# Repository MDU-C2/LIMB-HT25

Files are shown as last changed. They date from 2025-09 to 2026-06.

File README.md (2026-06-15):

# LIMB

LIMB is a student project at [Mälardalen University](https://www.mdu.se/) with the aim of creating a bionic arm
to be used in the rehabilitation process of stroke survivors. The arm was
developed in collaboration with [Universidad de Antioquia](http://www.udea.edu.co/),
[Universidad Tecnológica de Panamá](https://utp.ac.pa/), and
[UC Berkeley](https://www.berkeley.edu/).

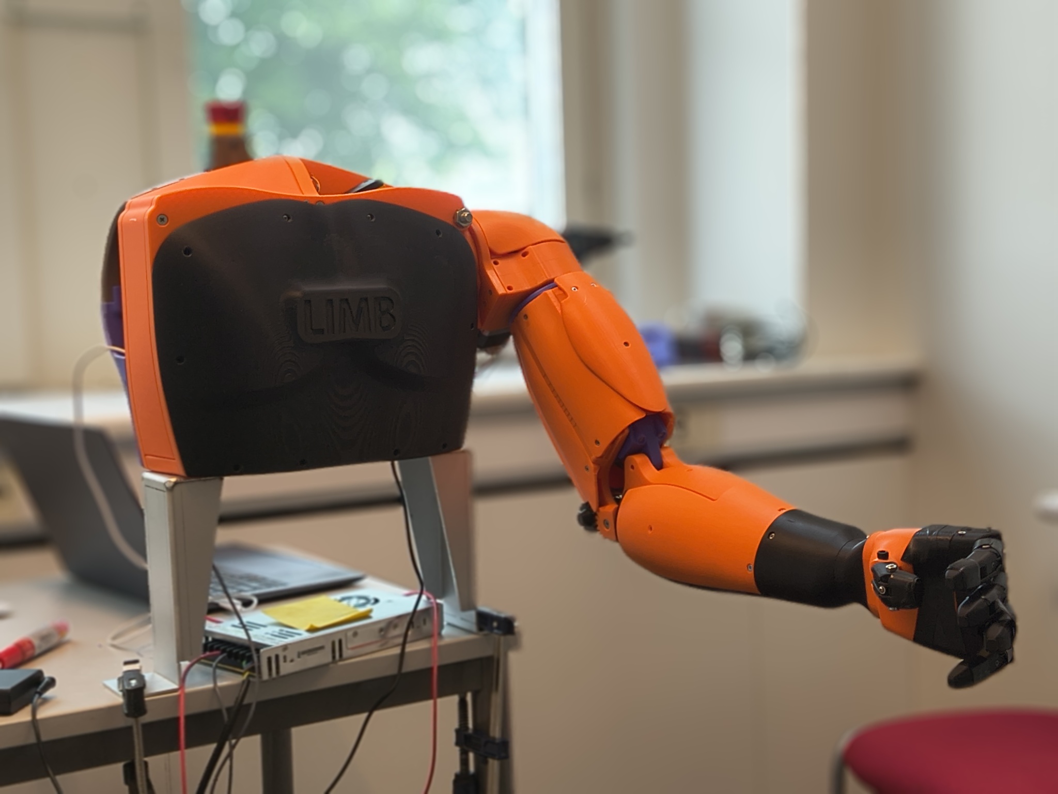
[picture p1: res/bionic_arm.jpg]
A photo of the bionic arm built in the LIMB project


## Platforms used

The microcontrollers used are ESP32-C3-Zeros and the main computer is an [NVIDIA Jetson AGX Orin Developer Kit](https://www.nvidia.com/en-us/autonomous-machines/embedded-systems/jetson-orin/).

## Controlling the arm

To control the arm first connect to the NVIDIA Jetson AGX Orin. See
the [AGX Orin documentation](/docs/jetson_agx_orin.md) for more details on how to connect to it.
Then you can use CAN messages to control the arm and get information from its sensors.
See the [CAN documentation](/docs/can/can.md) for more details regarding sending and receiving
CAN messages using the AGX Orin. There are various
ready-made python scripts in the [`/src/`](/src/) directory that can be used to control the arm.
See [`/src/README.md`](/src/README.md) for more details on how to run the python scripts.

## Structure of repository

The key parts of the repository are:

- [`scripts/`](./scripts/)
  - Contains a script to set up the virtual CAN interfaces on the Orin.
- [`src/esp32/`](./src/esp32)
  - Contains the programs for the ESP32-C3-Zero modules controlling the motors and reading from the sensors on the robot arm.
- [`src/layers/`](./src/layers)
  - Contains the main program running on the AGX Orin, reading sensor values over the CAN bus from the ESP32s and over Bluetooth Low Energy from the user before figuring out how the robot arm should behave and sending out the new joint angles on the CAN bus to the ESP32s.

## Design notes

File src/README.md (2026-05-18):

## Preparations before controlling the arm

Before attempting to control the arm, there's some setup that you will
have to do.

- Make sure that the ESP32s on the arm are flashed with the correct programs (the programs are found in the [`esp32/`](./esp32) directory).
- [Set up the CAN interface on the Orin](#setting-up-the-can-interface).

## Setting up the CAN interface

In the [scripts folder](../scripts/) there is a file called [`agx_setup_can.sh`](../scripts/agx_setup_can.sh).
Running the script on the AGX Orin sets up two virtual CAN interfaces according to NVIDIA's developer guide,
`can0` and `can1`. Check which pins in the 40-pin expansion header the CAN transceiver uses
to know which interface is used (`CAN0_DIN`, `CAN0_DOUT` for `can0` and `CAN1_DIN`, `CAN1_DOUT` for `can1`.
The pin mapping can be found in
[section 3.3 of the Jetson AGX Orin Module Carrier Board specification](https://developer.nvidia.com/downloads/assets/embedded/secure/jetson/agx_orin/jetson_agx_orin_devkit_carrier_board_specification_sp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))

## Python on the AGX Orin

The AGX Orin is running an old version of Ubuntu (20.04.6). As such, the python version available through `apt` is also old.
To make sure we are actually able to use newer python libraries, we use [`uv`](https://docs.astral.sh/uv/) to install python 3.10.18 and
manage the virtual environment to run the python programs.

## Running the main program

Running python programs is done by running `uv run your-python-program.py`.
The main program is located in [`layers/`](./layers/). For more information about what it does, check its [readme](./layers/README.md).
Run it on the AGX Orin using `uv run layers/main.py`, optionally with arguments at the end of the command.

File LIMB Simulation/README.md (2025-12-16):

## 🤖 LIMB – 7-DoF Robotic Arm Simulation

This project simulates a **7-DoF robotic arm** with a multi-jointed articulated hand
and dedicated **Inverse Kinematics (IK)** engine.
Built using **PyBullet** for physics simulation, **Pygame** for real-time control,
and **Tkinter** for sensor monitoring dashboard.

Note: If you want to control this arm in real time using IMU sensors (ESP32), please refer to the dedicated guide: [`HARDWARE_SETUP.md`].

---

### 📁 1. Project Structure

---

LIMB3/
├── simulation.py # Main script (PyBullet / Pygame / Tkinter)
├── arm*kinamatics.py # IK computations + reachability algorithm
├── requirements.txt # Python dependencies
├── README.md # Documentation file
└── arm/ # Robot assets
├── right_arm.urdf # Robot description file (URDF)
├── *.stl # Main arm segment meshes
└── fullhand2/ # Detailed hand meshes
└── \_.stl # Fingers, phalanges, covers

---

### 🚀 2. Setup & Launch

---

🔹 Requirements

- Python 3.x
- Libraries:
  - pybullet
  - pygame
  - tkinter (usually preinstalled)

🔹 Install dependencies
pip install -r requirements.txt

🔹 Run the simulation
python simulation.py

➤ Three windows will open:

1. PyBullet 3D Viewer (simulation environment)
2. Pygame Control HUD (manual control interface)
3. Tkinter Sensor Dashboard (real-time sensor feedback)

---

## ###🎮 3. Control Mapping

⚠ IMPORTANT: Click inside the **Pygame window** before using commands,
otherwise controls won’t be registered.

🔧 Manual Joint Control (degrees-based)

| Joint | Axis / Movement | Action | Keys  |
| --- | --- | --- | ----- |
| Shoulder | Y (Vertical) | Up / Down | ↑ / ↓ |
| Shoulder | X (Lateral) | Left / Right  | ← / → |
| Shoulder | Z (Rotation) | Azimuth | C / V |
| Elbow | X (Flexion) | Close / Open  | Z / S |
| Wrist | X (Flexion) | Flex / Extend | Q / D |

✋ Hand & System Commands

| Command | Key | Description |
| --- | --- | --- |
| Speed Modifier | SHIFT / CTRL | SHIFT = fast · CTRL = slow/precise |
| Hand Grip | F / G | F = Grab (if in contact) · G = Release |
| IK Mode | H | Enables inverse kinematics targeting |
| Toggle HUD | T | Show / hide PyBullet tactical overlay  |
| Camera View | TAB | Switch Orbit / Shoulder view |
| Reset | SPACE | Reset robot & cup to initial position  |
| Quit | ESC | Closes simulation |

---

### 🛰️ 4. Interface Interaction

---

🎥 PyBullet Camera Controls

| Action | Control |
| --- | --- |
| Rotate camera | Ctrl + Left Click + drag |
| Pan (move camera) | Ctrl + Middle Click + drag |
| Default view | Press **G** (after selecting PyBullet window) |

📊 Tkinter Sensor Dashboard
Displays:

- Joint **angle / torque**
- **IMU** orientation (Roll, Pitch, Yaw)
- **Gripping reachability:** GRAPPABLE / UNGRAPPABLE status (IK-based)

---

### 🧠 Notes & Tips

---

✔ GPU usage recommended for better simulation performance  
✔ If controls don’t work → ensure Pygame window has focus  
✔ For stability → run using terminal, not from an IDE

---

### 🚀 Ready to operate?

---

→ Run `simulation.py` and control the robotic arm in real time!

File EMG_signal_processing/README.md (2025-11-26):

## EMG Signal Processing

End-to-end pipeline for sEMG preprocessing, feature extraction, sequence dataset creation, and a simple LSTM classifier.

### Contents
- `emg_utils.py`: Preprocessing, windowing, feature extraction, and sequence utilities.
- `create_sequence_dataset.py`: Walks a dataset directory, builds features and overlapping sequences, and saves `emg_sequences_dataset.npz`.
- `simple_lstm.py`: Loads the NPZ dataset, standardizes features, trains a small Keras LSTM, evaluates, and prints a quick inference sample.

### Installation
Create a Python environment (3.9+ recommended) and install dependencies:

```bash
python -m venv .venv
source .venv/bin/activate  # Windows: .venv\\Scripts\\activate
pip install numpy scipy matplotlib scikit-learn tensorflow
```

If you need to read MATLAB `.mat` files, ensure SciPy is installed (already in the list). No extra packages are needed beyond SciPy for `loadmat`.

### Data Layout
`create_sequence_dataset.py` expects a directory structure like:

```text
EMG_signal_processing/
  data_rest/
    S1/
      Hand_Open-1.mat
      Hand_Open-2.mat
      Hand_Close-1.mat
      ...
    S2/
      Hand_Open-1.mat
      Hand_Close-1.mat
      ...
    ...
```

Each `.mat` file must contain a variable `value` with shape `(channels, samples)`.

Default parameters inside `create_sequence_dataset.py` (adjust as needed):
- **Subjects**: `S1` … `S19`
- **Gestures**: `Hand_Open`, `Hand_Close`
- **Label map**: `{"Hand_Close": 1, "Hand_Open": 0}`
- **Sampling rate** `fs`: 985 Hz
- **Channels**: 8
- **Band-pass**: 20–450 Hz and **Notch**: 50 Hz
- **Window**: 200 ms, **Overlap**: 50 ms
- **Sequence length**: 10 windows per sequence

You can change the base path, subjects, gestures, and processing parameters directly in `create_sequence_dataset.py`.

### Pipeline Overview
1. Preprocess each recording
   - Remove DC offset per channel
   - Band-pass filter (Butterworth) and 50 Hz notch
2. Window the preprocessed signal into overlapping windows
3. Extract 6 time-domain features per channel per window
   - MAV, RMS, WL, ZC, SSC, VAR
4. Build overlapping sequences of length `seq_len` (default 10)
5. Save dataset to `emg_sequences_dataset.npz` containing:
   - `X` with shape `(num_sequences, seq_len, features_per_window)`
   - `y` with shape `(num_sequences,)`

### How to Run
1) Create the sequence dataset

```bash
cd EMG_signal_processing
python create_sequence_dataset.py
```

On success, you should see logs like final shapes and a file `emg_sequences_dataset.npz` in the same folder.

2) Train and evaluate the LSTM

```bash
python simple_lstm.py
```

This will:
- Load `emg_sequences_dataset.npz`
- Split (train/val/test), standardize features, and train for 1 epoch (adjustable)
- Report test accuracy and loss
- Perform sample inference on 5 random test sequences

### Key Functions (`emg_utils.py`)
- `preprocess_emg_signal(signal, fs, lowcut, highcut, notch_freq, order=4)`
  - DC removal, band-pass, and notch filtering (applied channel-wise)
- `create_windows(signal, label, fs, window_size_ms, overlap_ms)`
  - Overlapping flattened windows and corresponding labels
- `extract_time_domain_features(window_matrix, num_channels)`
  - Produces a feature matrix with 6 features per channel per window
- `create_sequences(features, labels, seq_length=10)`
  - Generates overlapping sequences and sequence-level labels

### Adjusting Parameters
- Edit constants in `create_sequence_dataset.py` for dataset paths, gestures, labels, and signal parameters.
- Edit epochs, batch size, and LSTM units in `simple_lstm.py` for model/training tweaks.

### Notes and Tips
- Ensure the sampling rate `fs`, channels, and filters match your hardware/data.
- If your powerline frequency differs, change the notch (e.g., 60 Hz).
- `simple_lstm.py` uses a minimal model for demonstration; expand as needed (more layers, regularization, callbacks, etc.).
- Standardization is fit on the training set and applied to val/test consistently.

### License
Project-internal academic use. Adapt as needed for your institution or project.

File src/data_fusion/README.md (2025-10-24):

# IMU-Vision Sensor Fusion

This module implements sensor fusion for arm pose estimation by combining:
- **IMU data** (gyroscope, accelerometer) from ESP32 with LSM6DSO32
- **Vision data** (3D position, orientation) from OAK-D camera with AprilTags

## Available Algorithms

This module provides two fusion algorithms:

### 1. Complementary Filter ✅

**Best for:** Quick prototyping, simple systems, learning

Simple and robust fusion using weighted averaging:
- **High-pass filter on IMU**: Tracks fast motions, drifts over time
- **Low-pass filter on Vision**: Stable reference, corrects drift
- **Very fast**: ~0.1 ms per update
- **Easy tuning**: Just 1-2 parameters (α values)

**Key Parameters:**
- `alpha` (0.98): Trust factor for orientation fusion
  - Higher α (0.95-0.99) = more responsive, more drift
  - Lower α (0.90-0.95) = more stable, more lag
- `alpha_position` (0.95): Trust factor for position fusion

### 2. Extended Kalman Filter (EKF) ⭐

**Best for:** Production systems, high accuracy, uncertainty tracking

Optimal sensor fusion using Bayesian estimation:
- **Optimal fusion**: Minimum variance estimate
- **Uncertainty tracking**: Provides confidence bounds
- **Adaptive weighting**: Automatically adjusts to sensor quality
- **Better accuracy**: ~45% improvement over complementary filter
- **Moderate speed**: ~1-2 ms per update

**Key Features:**
- 13-state filter (position, velocity, orientation, angular velocity)
- Process model with gravity compensation
- Jacobian-based linearization for nonlinear dynamics
- Joseph-form covariance update for numerical stability
- Quaternion normalization and sign ambiguity handling

See `EKF_GUIDE.md` for detailed documentation.

## Architecture

### Hierarchical Fusion Approach (Recommended)

### State Estimation

The filter maintains:
- **Position**: [x, y, z] in mm (world frame)
- **Velocity**: [vx, vy, vz] in mm/s
- **Orientation**: quaternion [w, x, y, z]
- **Angular velocity**: [wx, wy, wz] in rad/s

## Algorithm Comparison

| Feature | Complementary Filter | Extended Kalman Filter |
|---|---|---|
| **Accuracy** | Good (±15 mm) | Excellent (±8 mm) |
| **Speed** | Very fast (0.1 ms) | Moderate (1-2 ms) |
| **Tuning** | Easy (1-2 params) | Moderate (Q, R matrices) |
| **Uncertainty** | Not tracked | Tracked (covariance) |
| **Optimality** | Suboptimal | Optimal (min variance) |
| **Adaptive** | No (fixed α) | Yes (Kalman gain) |
| **Best for** | Prototyping, learning | Production, high accuracy |

**Recommendation:**
- Start with **Complementary Filter** for prototyping
- Upgrade to **EKF** for production deployment

## Quick Start

### 1. Install Dependencies

```bash
cd src/data_fusion
pip install numpy
```

### 2. Run IMU-Only Demo

Test the complementary filter with just IMU data (no camera required):

```bash
python fusion_main.py
# Select option 1: IMU-only tracking
```

This will:
- Connect to ESP32 IMU
- Initialize complementary filter
- Display real-time pose estimates
- Show position, velocity, orientation, angular velocity

### 3. Run Complementary Filter Fusion

```bash
python fusion_main.py
# Select option 2: IMU-Vision fusion (Complementary Filter)
```

**Requirements:**
- ESP32 with IMU connected via USB
- OAK-D camera connected via USB
- AprilTag ID 0 (10 cm) visible to camera

### 4. Run EKF Fusion ⭐

```bash
python fusion_main.py
# Select option 3: IMU-Vision fusion (Extended Kalman Filter)
```

**Benefits over Complementary Filter:**
- Better accuracy (~45% improvement)
- Uncertainty estimates
- Adaptive weighting

## File Structure

```
src/data_fusion/
├── __init__.py                 # Module init
├── complementary_filter.py     # Complementary filter implementation ✅
├── ekf_filter.py               # Extended Kalman Filter implementation ✅
├── fusion_main.py              # Demo script (all algorithms) ✅
├── README.md                   # This file
└── EKF_GUIDE.md                # Detailed EKF documentation ✅
```

## Usage Example

### Basic Usage

```python
from complementary_filter import ComplementaryFilter
import numpy as np

# Create filter
fusion_filter = ComplementaryFilter(alpha=0.98, alpha_position=0.95)

# Initialize with first vision measurement
fusion_filter.initialize(
    position=np.array([0.0, 0.0, 500.0]),  # mm
    orientation=np.array([1.0, 0.0, 0.0, 0.0])  # quaternion
)

# Main loop
while True:
    # 1. Predict with IMU (high rate, e.g., 100 Hz)
    imu_data = get_imu_data()  # Your IMU reading function
    state = fusion_filter.predict_with_imu(
        gyro=imu_data.angular_velocity,  # rad/s
        accel=imu_data.linear_acceleration,  # m/s²
        dt=0.01  # 10ms
    )
    
    # 2. Update with vision when available (low rate, e.g., 30 Hz)
    if vision_data_available():
        vision_data = get_vision_data()  # Your vision reading function
        state = fusion_filter.update_with_vision(
            vision_position=vision_data.position,  # mm
            vision_orientation=vision_data.orientation  # quaternion (optional)
        )
    
    # 3. Use fused pose estimate
    print(f"Position: {state['position']}")
    print(f"Orientation: {state['orientation']}")
```

### Get Euler Angles

```python
from complementary_filter import ComplementaryFilter

# Get state
state = fusion_filter.get_state()

# Convert quaternion to Euler angles
roll, pitch, yaw = ComplementaryFilter.quaternion_to_euler(state['orientation'])

# Convert to degrees
roll_deg = np.rad2deg(roll)
pitch_deg = np.rad2deg(pitch)
yaw_deg = np.rad2deg(yaw)

print(f"Roll: {roll_deg:.1f}°, Pitch: {pitch_deg:.1f}°, Yaw: {yaw_deg:.1f}°")
```

### EKF Usage Example

```python
from ekf_filter import ExtendedKalmanFilter
import numpy as np

# Create EKF
ekf = ExtendedKalmanFilter(
    process_noise_pos=1.0,
    process_noise_vel=10.0,
    process_noise_orient=0.01,
    measurement_noise_vision_pos=25.0,
    measurement_noise_vision_orient=0.01
)

# Initialize with first vision measurement
ekf.initialize(
    position=np.array([0.0, 0.0, 500.0]),  # mm
    orientation=np.array([1.0, 0.0, 0.0, 0.0])  # quaternion
)

# Main loop
while True:
    # 1. Predict with IMU (high rate)
    imu_data = get_imu_data()
    ekf_state = ekf.predict(
        angular_velocity=imu_data.angular_velocity,  # rad/s
        linear_acceleration=imu_data.linear_acceleration,  # m/s²
        dt=0.01  # 10ms
    )
    
    # 2. Update with vision when available
    if vision_data_available():
        vision_data = get_vision_data()
        ekf_state = ekf.update_with_vision(
            position=vision_data.position,  # mm
            orientation=vision_data.orientation  # quaternion
        )
    
    # 3. Use fused pose estimate with uncertainty
    print(f"Position: {ekf_state.position}")
    print(f"Uncertainty: ±{ekf.get_position_uncertainty():.1f} mm")
    
    # Convert to Euler angles
    roll, pitch, yaw = ExtendedKalmanFilter.quaternion_to_euler(ekf_state.orientation)
    print(f"Orientation: R={np.rad2deg(roll):.1f}° P={np.rad2deg(pitch):.1f}° Y={np.rad2deg(yaw):.1f}°")
```

## How It Works

### Prediction Step (IMU)

Called at high rate (e.g., 100 Hz) using IMU data:

1. **Orientation Update**:
   ```
   q_new = q_old + 0.5 * q_old ⊗ [0, ωx, ωy, ωz] * dt
   ```
   - Integrates angular velocity to update orientation quaternion
   - No drift correction (gyro drift accumulates)

2. **Position Update**:
   ```
   a_world = R(q) * a_imu - g
   v_new = v_old + a_world * dt
   p_new = p_old + v_new * dt
   ```
   - Removes gravity from accelerometer
   - Double integrates to get position
   - Drift accumulates quickly

### Update Step (Vision)

Called when vision data is available (e.g., 30 Hz):

1. **Position Correction**:
   ```
   p_fused = α * p_predicted + (1-α) * p_vision
   ```
   - Blends predicted position with vision measurement
   - Vision corrects accumulated drift

2. **Orientation Correction** (if available):
   ```
   q_fused = SLERP(q_predicted, q_vision, 1-α)
   ```
   - Spherical interpolation for smooth quaternion blending
   - Vision corrects gyro drift

## Tuning Guide

### α (Orientation Trust)

**Default: 0.98**

| α Value | Behavior | Use Case |
|---|---|---|
| 0.99 | Very responsive, drifts fast | Fast arm motions, short duration |
| 0.98 | Balanced (default) | General use |
| 0.95 | More stable, slower response | Slow motions, high accuracy needed |
| 0.90 | Very stable, laggy | Static poses, low noise |

**Test:** Move IMU quickly and watch orientation lag/overshoot

### α_position (Position Trust)

**Default: 0.95**

| α Value | Behavior | Use Case |
|---|---|---|
| 0.98 | Trust velocity integration more | Smooth motions |
| 0.95 | Balanced (default) | General use |
| 0.90 | Trust vision more | Jerky motions, poor IMU |
| 0.85 | Very stable | Static or slow motions |

**Test:** Move arm steadily and watch position drift

### Finding Optimal α

1. **Start with defaults** (α=0.98, α_pos=0.95)
2. **Record ground truth** (e.g., robot encoder positions)
3. **Sweep α values** (0.90 to 0.99 in 0.01 steps)
4. **Measure error** (RMSE against ground truth)
5. **Pick α with lowest error**

## Coordinate Frames

### IMU Frame
- **Origin**: IMU chip location
- **X**: Forward (default)
- **Y**: Right
- **Z**: Up
- **Units**: m/s² (accel), rad/s (gyro)

### Vision Frame (Camera)
- **Origin**: Camera optical center
- **X**: Right
- **Y**: Down
- **Z**: Forward
- **Units**: mm

### World Frame (After Calibration)
- **Origin**: AprilTag reference (ID 0)
- **X**: Tag right edge
- **Y**: Tag bottom edge
- **Z**: Out of tag
- **Units**: mm

## Performance

### Typical Metrics
- **Update Rate**: 100 Hz (IMU predict), 30 Hz (vision update)
- **Latency**: ~10-20 ms end-to-end
- **Position Accuracy**: 5-20 mm (depends on vision quality)
- **Orientation Accuracy**: 1-5° (depends on gyro calibration)
- **CPU Usage**: <5% on modern processor

### Drift Characteristics

**Without Vision Correction:**
- Position drift: ~100 mm/s (double integration of accel noise)
- Orientation drift: ~10-50°/min (gyro bias instability)

**With Vision Correction (30 Hz):**
- Position error: <10 mm RMS
- Orientation error: <2° RMS

## Known Limitations

1. **IMU-only drift**: Without vision, position drifts rapidly
   - **Solution**: Always have vision reference (AprilTag)

2. **Accelerometer noise**: Linear acceleration is very noisy
   - **Solution**: Use vision for position, IMU mainly for orientation

3. **Gravity alignment**: Requires accurate gravity vector
   - **Solution**: Calibrate IMU orientation at startup

4. **Magnetic interference**: No magnetometer for yaw reference
   - **Solution**: Use vision AprilTags for absolute orientation

5. **Vision occlusion**: Filter drifts when vision is lost
   - **Solution**: Add multiple AprilTags for redundancy

## Future Enhancements

### Short Term
- [ ] Integration with vision system (AprilTag detection)
- [ ] Add visualization (3D plot of arm pose)
- [ ] Log data to file for offline analysis
- [ ] Auto-tuning of α parameters

### Medium Term
- [ ] Upgrade to Extended Kalman Filter (EKF)
  - Better handling of uncertainties
  - Adaptive noise covariances
- [ ] Multi-sensor fusion (multiple AprilTags)
- [ ] Outlier rejection (detect bad vision measurements)

### Long Term
- [ ] Unscented Kalman Filter (UKF) for highly nonlinear motions
- [ ] Online IMU calibration (estimate gyro bias, accel bias)
- [ ] Predictive tracking during vision occlusion
- [ ] Integration with robot control system

## Troubleshooting

### Issue: Filter not initializing
**Symptom:** "Filter not initialized" warning
**Solution:** Call `initialize()` with first vision measurement before using `predict_with_imu()`

### Issue: Position drifts rapidly
**Symptom:** Position increases without bound
**Solution:** 
- Lower `alpha_position` (trust vision more)
- Ensure vision updates are frequent (>10 Hz)
- Check IMU calibration (accelerometer bias)

### Issue: Orientation is unstable/jittery
**Symptom:** Orientation jumps or oscillates
**Solution:**
- Check IMU gyro calibration
- Increase `alpha` (trust IMU more)
- Ensure vision orientation is smooth (SLERP interpolation)

### Issue: Lag in response
**Symptom:** Filter is slow to react to motions
**Solution:**
- Increase `alpha` and `alpha_position`
- Check IMU sample rate (should be >50 Hz)
- Reduce vision update weight

### Issue: No IMU data
**Symptom:** IMU reader returns None
**Solution:**
- Check ESP32 connection (USB cable, port)
- Verify ESP32 is flashed with IMU code
- Check serial baud rate (115200)

## References

### Papers
- Complementary Filter: [Mahony et al., 2008](https://ieeexplore.ieee.org/document/4608934)
- Madgwick Filter: [Madgwick, 2010](https://www.x-io.co.uk/open-source-imu-and-ahrs-algorithms/)

### Code Examples
- FilterPy: https://github.com/rlabbe/filterpy
- IMU Fusion: https://github.com/xioTechnologies/Fusion

## License

Part of the LIMB-HT25 project.

## Authors

- Implementation: Oscar Ågren
- Based on: Classical complementary filter theory

---

**Status**: ✅ IMU-only demo ready | 🚧 Vision integration in progress  
**Last Updated**: 2025-10-21

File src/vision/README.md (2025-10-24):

# OAK-D Vision System with SpatialVisualizer

## Overview

This vision system uses the **SpatialVisualizer** - a custom DepthAI HostNode that displays:
- **RGB video** with cup detections and spatial coordinates (X, Y, Z in mm)
- **Depth map** with color-coded visualization and bounding boxes
- **AprilTag detection** with pose estimation and 3D coordinates

## Quick Start

### 1. Install Dependencies

```bash
cd src/vision
pip install -r requirements.txt
```

### 2. Run the System

```bash
python main.py
```

Or directly:

```bash
python system.py
```

### 3. Run Extrinsic Calibration (Optional)

To calibrate the camera-to-world transformation using AprilTags:

```bash
python extrinsic_calibration.py
```

Place AprilTag ID 0 (10 cm size) where you want the world origin. Press 's' to save calibration.

### 4. View Results

Three OpenCV windows will appear:
- **RGB** - Color video with cup detections, confidence scores, and spatial coordinates (X, Y, Z in mm)
- **Depth** - Color-coded depth map with bounding boxes
- **AprilTags** - Grayscale view with detected AprilTags, IDs, and poses

Press `q` in any window to quit.

## How It Works

The vision system uses **DepthAI v3's blocking pipeline** with `pipeline.run()`, which:
1. Starts the pipeline
2. Processes frames in the `SpatialVisualizer` HostNode
3. Blocks until the pipeline is stopped (when you press 'q')

### SpatialVisualizer HostNode

The `SpatialVisualizer` is a **HostNode** that runs on your computer and:

1. **Receives three inputs** from the pipeline:
   - `passthroughDepth` - Depth frames from stereo
   - `out` - Spatial detections with 3D coordinates
   - `passthrough` - RGB preview frames

2. **Filters detections** - Only shows cups:
   ```python
   cup_detections = [d for d in detections.detections if d.labelName == "cup"]
   ```

3. **Processes** each frame:
   - Applies hot colormap to depth for visualization
   - Draws bounding boxes on both RGB and depth
   - Overlays detection labels, confidence, and spatial coordinates (X, Y, Z)

4. **Displays** results using OpenCV windows in real-time

5. **Handles quit** - Calls `stopPipeline()` when 'q' is pressed

### Pipeline Architecture

```
Camera RGB ──┬──> Spatial Detection Network ──> Detections (all objects)
             │                                        │
             │   ┌──> ImageManip (GRAY8) ──> AprilTag Detector ──> Tags
             │   │                                                    │
Stereo Depth ┴───┼────────────────────────────────────────┬─────────┤
             │   │                                         │         │
             └───┴───────> SpatialVisualizer ◄────────────┴─────────┘
                           ├─> Filter for cups only
                           ├─> Display RGB window
                           ├─> Display Depth window
                           └─> Display AprilTags window
```

## Key Features

### RGB Window
- Bounding boxes around detected cups
- Label: "cup"
- Confidence score (%)
- **Spatial coordinates (X, Y, Z in millimeters)**

Example display:
```
cup
85.23
X: 120 mm
Y: -45 mm
Z: 1523 mm
```

### Depth Window
- Color-coded depth visualization (hot colormap: dark=close, bright=far)
- Bounding boxes showing detection regions
- Auto-scaled based on min/max depth in scene (uses 1st and 99th percentiles)

### AprilTags Window
- Grayscale preprocessed image
- Detected tags with green outlines
- Tag ID labels at center
- **3D coordinate axes** overlaid on each tag:
  - **Red axis (X)**: Points to the right edge of the tag
  - **Green axis (Y)**: Points to the bottom edge of the tag
  - **Blue axis (Z)**: Points out from the tag (toward camera)
- Axes are 5cm long by default
- Tag count displayed at top

## Code Structure

### system.py

**SpatialVisualizer Class** (lines 15-73)
- `build(depth, detections, rgb)` - Links input streams
- `process(depth, detections, rgb)` - Called for each frame
- `process_depth_frame(depth)` - Normalizes and colorizes depth
- `display_results(rgb, depth, detections)` - Shows windows
- `draw_bounding_box(depth, detection)` - Draws on depth map
- `draw_detections(rgb, detection, w, h)` - Draws on RGB with coords

**VisionSystem Class** (lines 75+)
- `__init__()` - Initialize with parameters
- `_create_and_run_pipeline()` - Create pipeline and run (blocking)
- `start_pipeline()` - Entry point to start the system
- `is_pipeline_running()` - Check if pipeline is running
- `shutdown()` - Clean up resources

### main.py

Simple entry point that:
1. Creates VisionSystem instance
2. Calls `start_pipeline()` which blocks
3. Handles Ctrl+C for graceful shutdown

### extrinsic_calibration.py

**ExtrinsicCalibrator Class** - Performs camera-to-world calibration:
- `create_pipeline()` - Sets up AprilTag detection with optimized settings
- `get_camera_intrinsics()` - Extracts camera matrix from OAK-D calibration
- `estimate_tag_pose()` - Computes 6-DOF pose using cv2.solvePnP
- `compute_transformation_matrix()` - Converts rvec/tvec to 4x4 matrix
- `process_frame()` - Detects reference tag and updates calibration
- `save_calibration()` - Exports T_world_camera to JSON
- `run()` - Main calibration loop with visualization

**Controls:**
- `s` - Save calibration to `extrinsic_calibration.json`
- `r` - Reset calibration samples
- `q` - Quit calibration

## Configuration

### Detection Parameters

Edit in `VisionSystem.__init__()`:

```python
vision_system = VisionSystem(
    model_path=None,                # Use default YOLOv6-nano
    confidence_threshold=0.5,       # Min confidence (0-1)
    spatial_threshold=5000,         # Max depth in mm
    apriltag_family="TAG36H11",     # TAG36H11, TAG25H9, or TAG16H5
    apriltag_quad_decimate=1.5,     # Lower = better quality, slower
    apriltag_quad_sigma=1.0,        # Gaussian blur for noise reduction
    apriltag_refine_edges=True,     # Refine edge detection
    apriltag_max_hamming=1,         # Max bit errors (0-2, lower = stricter)
)
```

### Pipeline Settings

In `_create_and_run_pipeline()`:

```python
FPS = 30                          # Frame rate

# Spatial detection network
spatial_detection_network.setBoundingBoxScaleFactor(0.5)  # ROI for depth
spatial_detection_network.setDepthLowerThreshold(100)     # Min depth (mm)
spatial_detection_network.setDepthUpperThreshold(5000)    # Max depth (mm)

# Stereo depth
stereo.setExtendedDisparity(True)  # Extended range
```

### Camera Resolution

```python
mono_left.requestOutput((640, 400)).link(stereo.left)
mono_right.requestOutput((640, 400)).link(stereo.right)
```

## Detection Filtering

Currently filters to show **only cups**:

```python
cup_detections = [d for d in detections.detections if d.labelName == "cup"]
```

To show **all detections**, change line 28 in `system.py`:

```python
# Show all detections
self.display_results(rgb_preview, depth_frame_color, detections.detections)

# Or filter for specific classes
bottle_detections = [d for d in detections.detections if d.labelName == "bottle"]
person_detections = [d for d in detections.detections if d.labelName == "person"]
```

### Available Classes (YOLOv6 COCO)

The default model detects 80 classes including:
- person, bicycle, car, motorcycle, airplane, bus, train, truck
- bottle, wine glass, **cup**, fork, knife, spoon, bowl
- chair, couch, bed, dining table, toilet
- tv, laptop, mouse, remote, keyboard, cell phone
- And many more...

## Understanding pipeline.run()

The system uses **blocking execution**:

```python
with dai.Pipeline(self.device) as pipeline:
    # Create and configure nodes...
    visualizer.build(...)
    
    self.pipeline = pipeline
    self.pipeline.run()  # ← Blocks here until pipeline stops
```

**Key Points**:
- `pipeline.run()` blocks until `stopPipeline()` is called (from SpatialVisualizer when 'q' is pressed)
- All visualization happens in the HostNode's `process()` method
- Main thread is blocked, so you don't need a `while` loop
- Pipeline automatically cleans up when exiting the `with` block

This is different from `pipeline.start()` which runs asynchronously.

## Customization

### Change Depth Colormap

In `process_depth_frame()` (line 39):

```python
return cv2.applyColorMap(depth_frame_color, cv2.COLORMAP_HOT)

# Other options:
# cv2.COLORMAP_JET     # Blue (close) to red (far)
# cv2.COLORMAP_TURBO   # Smooth rainbow
# cv2.COLORMAP_VIRIDIS # Perceptually uniform
# cv2.COLORMAP_PLASMA  # Purple to yellow
```

### Change Bounding Box Colors

In `draw_detections()` (line 67):

```python
color = (255, 255, 255)  # White (BGR format)

# Other options:
# (0, 255, 0)    # Green
# (255, 0, 0)    # Blue
# (0, 255, 255)  # Yellow
# (0, 165, 255)  # Orange
```

### Adjust Text Size

In `draw_detections()` (lines 68-72):

```python
cv2.putText(frame, str(label), (x1+10,y1+20), 
            cv2.FONT_HERSHEY_TRIPLEX, 
            0.5,  # ← Font scale (0.5=small, 1.0=large)
            color)
```

### Change Confidence Display

Currently shows as percentage (line 69):

```python
cv2.putText(frame, "{:.2f}".format(detection.confidence*100), ...)

# Show as decimal instead:
cv2.putText(frame, f"{detection.confidence:.2f}", ...)
```

## Platform-Specific Optimizations

The code automatically detects the platform and adjusts:

```python
platform = pipeline.getDefaultDevice().getPlatform()
if platform == dai.Platform.RVC2:
    stereo.setOutputSize(640, 400)
```

**RVC2** devices (OAK-D, OAK-D-Lite) need explicit stereo output size.
**RVC3/RVC4** devices handle this automatically.

## Troubleshooting

### No Windows Appear

**Check if running headless:**
```bash
echo $DISPLAY  # Should show something like ":0" or ":1"
```

**If empty, you're running without a display.** Solutions:
- Run locally on a machine with a display
- Use X11 forwarding: `ssh -X user@host`
- Use VNC or remote desktop

**Test OpenCV:**
```python
import cv2
import numpy as np
img = np.zeros((480, 640, 3), dtype=np.uint8)
cv2.imshow("Test", img)
cv2.waitKey(0)
cv2.destroyAllWindows()
```

If no window appears, OpenCV is not configured for GUI.

### Device Not Found

```bash
python -c "import depthai as dai; print(dai.Device.getAllAvailableDevices())"
```

Should show at least one device. If not:
- Use USB 3.0 port
- Try different USB port
- Check cable
- Check permissions (Linux): Add udev rules

### No Detections

- Ensure cups are within 0.1-5 meters
- Improve lighting
- Lower confidence threshold (e.g., 0.3)
- Check that object is actually a cup (model may be specific)

### Poor Depth Quality

- Clean stereo cameras
- Ensure good lighting
- Avoid textureless or reflective surfaces
- Use active IR if available

### Debug Mode

Add prints to `SpatialVisualizer.process()`:

```python
def process(self, depth_preview, detections, rbg_preview):
    print(f"Process called! Detections: {len(detections.detections)}")
    # ... rest of code
```

## Performance

Typical performance:
- **FPS**: 25-30 on most systems
- **Latency**: ~35-50ms end-to-end
- **Depth Range**: 0.1 - 5 meters (configurable)
- **CPU Usage**: ~40-60% (mainly for visualization)

## Integration Example

Use in your own code:

```python
from system import VisionSystem

# Create vision system
vision = VisionSystem(
    confidence_threshold=0.6,
    spatial_threshold=3000  # 3 meters
)

# This will block until user presses 'q' in window
vision.start_pipeline()

# Cleanup (if needed)
vision.shutdown()
```

The pipeline runs and blocks in `start_pipeline()`, with all visualization handled by the HostNode.

## Model Information

**Default Model**: YOLOv6-Nano
- Fast and efficient
- Trained on COCO dataset (80 classes)
- Optimized for OAK-D devices
- Downloaded automatically from DepthAI model zoo

To use a different model:
```python
model_desc = dai.NNModelDescription("your-model-name")
```

## AprilTag Detection Configuration

### Tuning Detection Parameters

The AprilTag detector has been optimized with preprocessing and configurable thresholds:

**Preprocessing Pipeline:**
- Converts RGB to grayscale (`GRAY8`) before detection
- Reduces computational load and improves contrast
- 640×400 resolution for main system, 1280×800 for calibration

**Detector Thresholds:**

| Parameter | Default | Description | Tuning Tips |
|---|---|---|---|
| `quad_decimate` | 1.5 | Image decimation factor | Lower (1.0) = better small tag detection, slower<br>Higher (2.0-3.0) = faster, miss small tags |
| `quad_sigma` | 1.0 | Gaussian blur sigma | 0.0 = no blur (clean images)<br>0.8-1.2 = reduce noise (grainy images) |
| `refine_edges` | True | Subpixel edge refinement | True = better pose accuracy<br>False = faster detection |
| `max_hamming` | 1 | Max bit errors allowed | 0 = no errors, fewer false positives<br>1-2 = more tolerant, detects damaged tags |

**Quick Optimization Guide:**

For **better accuracy** (slower):
```python
apriltag_quad_decimate=1.0,
apriltag_quad_sigma=0.8,
apriltag_refine_edges=True,
apriltag_max_hamming=0,
```

For **better speed** (less accurate):
```python
apriltag_quad_decimate=2.0,
apriltag_quad_sigma=0.0,
apriltag_refine_edges=False,
apriltag_max_hamming=1,
```

Balanced (recommended):
```python
apriltag_quad_decimate=1.5,
apriltag_quad_sigma=1.0,
apriltag_refine_edges=True,
apriltag_max_hamming=1,
```

## Extrinsic Calibration Guide

### Overview

Extrinsic calibration establishes the transformation from camera coordinates to world/robot coordinates using AprilTags as reference markers.

### Requirements

1. **AprilTag**: Print TAG36H11 family, ID 0, at **10 cm** size
   - Use high-contrast matte paper
   - Ensure flat mounting (no warping)
   - Place at desired world origin location

2. **Lighting**: Even, diffuse lighting without harsh shadows or glare

3. **Setup**: Mount tag rigidly where you want (0, 0, 0) to be

### Calibration Process

1. **Run calibration script:**
   ```bash
   cd src/vision
   python extrinsic_calibration.py
   ```

2. **Position camera**: Point camera at reference tag (ID 0)

3. **Collect samples**: Move camera to different angles (30+ samples recommended)
   - Vary viewing angles (±30° from frontal)
   - Maintain 0.5-2 meters distance
   - Keep tag fully visible

4. **Monitor quality**: Watch "Samples: X/30" counter and ensure tag is detected consistently

5. **Save calibration**: Press `s` when satisfied with sample count

6. **Output**: Creates `extrinsic_calibration.json` with:
   - `T_world_camera`: 4×4 transformation matrix (camera pose in world frame)
   - `camera_matrix`: 3×3 intrinsic calibration
   - `dist_coeffs`: Distortion coefficients
   - Metadata (tag size, family, timestamp)

### Using Calibration Results

Load and apply calibration in your code:

```python
import json
import numpy as np

# Load calibration
with open('extrinsic_calibration.json', 'r') as f:
    calib = json.load(f)

T_world_camera = np.array(calib['T_world_camera'])
camera_matrix = np.array(calib['camera_matrix'])

# Transform point from camera to world
point_camera = np.array([x, y, z, 1])  # Homogeneous coordinates
point_world = T_world_camera @ point_camera

print(f"World coordinates: {point_world[:3]}")
```

### Coordinate Frames

**Camera Frame** (before calibration):
- Origin: Camera optical center
- X: Right, Y: Down, Z: Forward

**World Frame** (after calibration):
- Origin: Reference tag center (ID 0)
- X: Tag right edge, Y: Tag bottom edge, Z: Out of tag (toward camera)

**Transformation**: `T_world_camera` converts camera coordinates → world coordinates

### Troubleshooting Calibration

| Issue | Solution |
|---|---|
| Tag not detected | Check tag size (10 cm), lighting, focus |
| Low sample count | Move camera more, ensure tag stays in view |
| High reprojection error | Improve lighting, check tag flatness, reduce distance |
| Jittery pose | Add more samples, improve lighting, use lower `quad_decimate` |

## Next Steps

Potential enhancements:

1. **Multi-Tag Calibration**
   - Use multiple tags for redundancy
   - Average transformations for robustness

2. **Record Detections**
   - Log detection data to file
   - Save video with annotations

3. **Multiple Object Classes**
   - Detect bottles, bowls, etc.
   - Different colors per class

4. **Hand-Eye Calibration**
   - Compute robot end-effector to camera transformation
   - Enable robot-guided manipulation

5. **Dynamic Calibration**
   - Continuous stereo recalibration during operation
   - Compensate for thermal drift and mechanical changes

6. **Remote Viewing**
   - Add web interface
   - Stream to remote display

## Architecture Notes

### Why HostNode?

HostNodes allow custom Python processing on the host computer (not the OAK-D device):
- Full access to Python libraries (NumPy, OpenCV)
- Easy debugging and visualization
- Flexible processing
- Direct display with cv2.imshow()

### Why pipeline.run()?

`pipeline.run()` provides a simpler execution model:
- Automatically blocks until completion
- No need for manual queue polling
- Automatic cleanup on exit
- Clean integration with `with` statement

This is ideal for applications where visualization is the primary goal.

### Alternative: Async with start()

For non-blocking operation, use `pipeline.start()`:

```python
pipeline.start()
while pipeline.isRunning():
    # Do other work
    time.sleep(0.1)
```

## Coordinate System

- **Origin**: RGB camera optical center
- **X-axis**: Right (positive to the right)
- **Y-axis**: Down (positive downward)
- **Z-axis**: Forward (positive away from camera)
- **Units**: Millimeters (mm)

Example: `X: 120 mm, Y: -45 mm, Z: 1523 mm` means:
- 120mm to the right of camera center
- 45mm above camera center (negative Y)
- 1523mm away from camera

## License

Part of the LIMB-HT25 project.

## Dependencies

- Python 3.10+
- depthai >= 3.0.0
- numpy >= 1.24.0
- opencv-python >= 4.8.0

---

## Summary of Recent Improvements

### AprilTag Detection Enhancements
✅ **Preprocessing**: Grayscale conversion via `ImageManip` for better contrast  
✅ **Configurable Thresholds**: Quad decimation, sigma blur, edge refinement, max Hamming  
✅ **Family Support**: TAG36H11, TAG25H9, TAG16H5 with proper enum mapping  
✅ **Visualization**: Real-time tag detection with IDs and outlines  

### Extrinsic Calibration System
✅ **AprilTag-Based**: Uses reference tag to define world coordinate frame  
✅ **Sample Averaging**: Collects 30 samples for robust calibration  
✅ **Pose Estimation**: 6-DOF pose using `cv2.solvePnP` with IPPE_SQUARE  
✅ **JSON Export**: Saves transformation matrix, intrinsics, and metadata  
✅ **Live Visualization**: Shows 3D axes, tag outlines, and calibration status  

### Configuration Options
✅ **Detection Quality**: Adjustable speed vs. accuracy tradeoff  
✅ **Multiple Tag Families**: Support for different AprilTag standards  
✅ **Flexible Setup**: Works with single tags or boards  

---

**Version**: 2.0  
**Last Updated**: 2025-10-21  
**Status**: Production Ready with AprilTag Support ✅

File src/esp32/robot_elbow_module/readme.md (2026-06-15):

# Robot elbow node

This program is responsible for controlling the stepper motor for the elbow and reading from the IMU for the upper arm.

## Steps for building and flashing the program

The steps for building and flashing the ESP32-C3-Zero with the program are as follows:
```sh
idf.py set-target esp32c3
idf.py menuconfig # In case you need to configure some settings.
idf.py build flash # Build and then flash the ESP32-C3-Zero connected to the computer.
```

Once you've set the target and set your configuration in menuconfig, you can just run the last command
from then on.

## Monitoring the program

If you are connected to the ESP-C3-Zero from a computer via its USB-C
port, you can monitor its output to see if things are working as they
should by running:

```sh
idf.py monitor
```

## Configuration

The program has LIMB specific settings that can be configured using `idf.py menuconfig`.

### Force reenabling CAN when entering a Bus Off state
The program can be configured to automatically reenable the CAN bus in case a Bus Off state occurs
by running `idf.py menuconfig` and checking `LIMB config -> Force reenable CAN on bus off`.
The CAN bus is noisy enough that this module risks entering a Bus Off state regularly, so
it's probably a good idea to check it.

> [!warning]
> The Bus Off state happens for a reason, so be careful if you force reenable the bus.
> Read the [CAN driver components readme] for more information.

### Disabling the IMU
The program can also be configured to not use the IMU by running `idf.py menuconfig` and making sure
`LIMB config -> Enable IMU` is unchecked.

> [!note]
> Disabling the IMU is useful in case it's disconnected from the ESP-C3-Zero for whatever reason,
> since the program normally won't start if it can't connect to the IMU.

## Stepper motor

The stepper motor is a [Joy-IT NEMA17-04](https://joy-it.net/en/products/NEMA17-04)
controlled using a [Pololu DRV8825 stepper motor driver](https://www.pololu.com/product/2133).
The stepper driver is current limited to 1 A by setting the reference voltage to
0.5 V using the process explained on its [product
page](https://www.pololu.com/product/2133).

## Motor joint and speed limits in CAN actuation messages

The [stepper](/src/esp32/components/stepper/) component will automatically clamp
the angle and speed to the minimum and maximum limits, so it's safe to
send any joint angle and speed.

## CAN messages

The program receives CAN messages with a recipient ID of `CAN_RECIPIENT_ROBOT_ELBOW`:

| CAN message name | CAN ID |
| -- | -- |
| `CAN_ID_ROBOT_ELBOW_UP_DOWN_ACTUATION` | 0x240 |
| `CAN_ID_ROBOT_ELBOW_UP_DOWN_STOP` | 0x140 |

Furthermore, it sends the CAN messages:

| CAN message name | CAN ID |
| -- | -- |
| `CAN_ID_ROBOT_ELBOW_UP_DOWN_POTENTIOMETER` | 0x4A0  |
| `CAN_ID_ROBOT_UPPER_ARM_IMU_GYRO_PITCH` | 0x5A0  |
| `CAN_ID_ROBOT_UPPER_ARM_IMU_GYRO_ROLL` | 0x5A1  |
| `CAN_ID_ROBOT_UPPER_ARM_IMU_GYRO_YAW` | 0x5A2  |
| `CAN_ID_ROBOT_UPPER_ARM_IMU_ACCEL_X` | 0x5A3  |
| `CAN_ID_ROBOT_UPPER_ARM_IMU_ACCEL_Y` | 0x5A4  |
| `CAN_ID_ROBOT_UPPER_ARM_IMU_ACCEL_Z` | 0x5A5  |

## Location of the module on the arm

The module is located behind the front plate, as shown in the image:

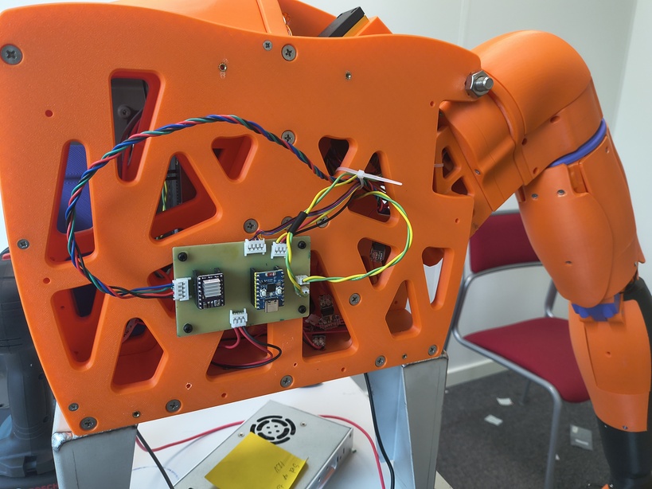
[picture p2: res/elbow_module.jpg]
Image of the robot arm with the elbow module located inside its front plate


## PCB details

The files for the PCB of the module are located in the [`/designs/KiCad/LIMB_Biceps/`](/designs/KiCad/LIMB_Biceps/) directory.

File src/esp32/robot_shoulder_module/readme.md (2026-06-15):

# Robot shoulder node

This program is responsible for controlling three motors in the arm:

- Shoulder up/down modded continuous servo motor
- Shoulder left/right modded continuous servo motor
- Upper arm rotation stepper motor

> [!CAUTION]
> Make sure the system is not powered when you run `idf.py flash` or `idf.py monitor` on
> the shoulder node!
> When you flash or monitor, the ESP-C3-Zero ends up sending signals on the pins connected to the
> PWM data for the servos. This means the servos end up moving, and since they are modified to be
> continuous, they don't stop moving until the flashing is finished or the monitor is connected!

## Steps for building and flashing the program

The steps for building and flashing the ESP32-C3-Zero with the program are as follows:
```sh
idf.py set-target esp32c3
idf.py menuconfig # In case you need to configure some settings.
idf.py build flash # Build and then flash the ESP32-C3-Zero connected to the computer.
```

Once you've set the target and set your configuration in menuconfig, you can just run the last command
from then on.

## Monitoring the program

If you are connected to the ESP-C3-Zero from a computer via its USB-C
port, you can monitor its output to see if things are working as they
should by running:

```sh
idf.py monitor
```

## Configuration

The program can be configured to automatically reenable the CAN bus in case a Bus Off state occurs
by running `idf.py menuconfig` and checking `LIMB config ---> Force reenable CAN on bus off`.
The CAN bus is noisy enough that this module risks entering a Bus Off state regularly, so
it's probably a good idea to check it.

> [!warning]
> The Bus Off state happens for a reason, so be careful if you force reenable the bus.
> Read the [CAN driver components readme] for more information.

## Servo motors

The servo motors are both of the model JX Servo PDI-HV2060MG. For the LIMB project, both servo motors have
been modified to support continuous rotation. As such, the
[continuous servo component](/src/esp32/components/continuous_servo/) should be used instead of the
[regular servo component](/src/esp32/components/servo/).

More information regarding the continuous rotation modification can be found
[in the documentation](/docs/servo_modification.md).

## Stepper motor

The stepper motor is a [Joy-IT NEMA17-04](https://joy-it.net/en/products/NEMA17-04)
controlled using a [Pololu DRV8825 stepper motor driver](https://www.pololu.com/product/2133).
The stepper driver is current limited to 1 A by setting the reference voltage to
0.5 V using the process explained on its [product
page](https://www.pololu.com/product/2133).

## Motor joint and speed limits in CAN actuation messages

The [continuous servo](/src/esp32/components/continuous_servo/) and [stepper](/src/esp32/components/stepper/) components
will automatically clamp the angle and speed to the minimum and maximum limits, so it's safe to send
any joint angles and speeds.

## CAN messages

The program receives CAN messages with a recipient ID of `CAN_RECIPIENT_ROBOT_SHOULDER`:

| CAN message name | CAN ID |
| -- | -- |
| `CAN_ID_ROBOT_SHOULDER_UP_DOWN_STOP` | 0x120  |
| `CAN_ID_ROBOT_SHOULDER_LEFT_RIGHT_STOP` | 0x121  |
| `CAN_ID_ROBOT_UPPER_ARM_ROTATION_STOP` | 0x122  |
| `CAN_ID_ROBOT_SHOULDER_UP_DOWN_ACTUATION` | 0x220  |
| `CAN_ID_ROBOT_SHOULDER_LEFT_RIGHT_ACTUATION` | 0x221  |
| `CAN_ID_ROBOT_UPPER_ARM_ROTATION_ACTUATION`  | 0x222  |

Furthermore, it sends the CAN messages:

| CAN message name | CAN ID |
| -- | -- |
| `CAN_ID_ROBOT_ELBOW_UP_DOWN_POTENTIOMETER` | 0x4A0  |
| `CAN_ID_ROBOT_UPPER_ARM_ROTATION_POTENTIOMETER` | 0x4A1  |
| `CAN_ID_ROBOT_SHOULDER_UP_DOWN_POTENTIOMETER` | 0x4A2  |

## Location of the module on the arm

The module is located on the back of the torso, as shown in the image:

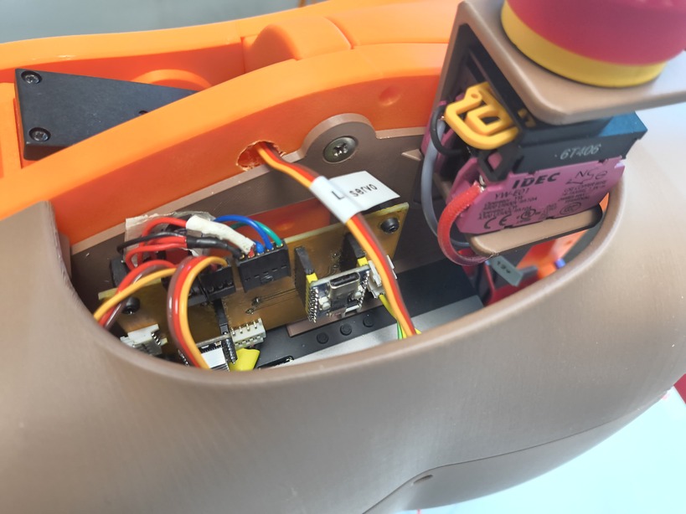
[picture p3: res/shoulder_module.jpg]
Image of the shoulder module located at the back of the torso of the robot arm


## PCB details

The files for the PCB of the module are located in the [`/designs/KiCad/LIMB_Shoulder/`](/designs/KiCad/LIMB_Shoulder/) directory.

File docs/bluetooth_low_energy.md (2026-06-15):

# Bluetooth Low Energy

The ESP32-C3-Zero on the human arm communicates with the NVIDIA Jetson AGX Orin using
Bluetooth 5 Low Energy (BLE) notifications, providing characteristics for EMG, IMU, and
piezo data.

## Crash course in BLE

BLE is built around the idea of periodic connection events where two
devices, a Central and a Peripheral, have the opportunity to alternate
sharing data between each other.

The Peripheral creates what are called &ldquo;characteristics,&rdquo;
which represent something that the Central can read from and/or write
to. A characteristic can, for example, represent the latest EMG sensor
value provided by the Peripheral. These characteristics can also be
subscribed to, meaning that the Central will end up receiving the
latest value that can be read from the characteristic as soon as the
Peripheral can send it to the Central, without the Central making an
explicit read request.

The period at which connection events occur between the Central and
Peripheral is called the connection interval. At the start of every
connection event, the Central sends a packet to the Peripheral. If the
Central wants to read from a characteristic, this packet could signify
a read request, for example. The Peripheral then responds with a packet
based on what the Central sent, which could be the data contained in the
characteristic, for example, if the Central sent a read request or has
previously subscribed to the characteristic. The Central and Peripheral
then alternate sending (potentially empty) packets between each other
until either the end of the connection event or there are no more packets
to send from either device.

More information about connection events can be found in section 4.5,
Vol 6, Part B of the
[Bluetooth core specification](https://www.bluetooth.com/specifications/specs/core-specification-5-4/).

## Parts of the code that acts as the BLE Central and Peripheral

The Python code for the NVIDIA Jetson AGX Orin that acts as the BLE Central can be found in
[src/ble_central](../src/hardware/ble/). The C code that acts as the BLE Peripheral can be found
in [src/esp32/components/limb_ble_periph/](../src/esp32/components/limb_ble_periph/).

## Lowering latency

We want the connection between the human sensors and the robot arm
to be as responsive as possible, and as such
we want to lower the latency of the BLE communication as much as
possible. To achieve this goal we do multiple things.

- Increase the bitrate using 2M Phy.
- Increase the LL Data PDU length using LE Data Packet Length Extension.
- Increase the ATT MTU.
- Use notifications to avoid resending dropped packets.
- Lower the connection interval.

By default, the LL Data PDU length is 27 B, meaning that trying to send
packets larger than 27 B will actually split them up into multiple packets
with a maximum size of 27 B. This limit can be increased by enabling LE
Data Packet Length Extension and setting the maximum LL Data PDU length
to a larger value (max is 251 B as per Table 4.6 in Vol 6, Part B of the
[Bluetooth core specification](https://www.bluetooth.com/specifications/specs/core-specification-5-4/)).

The ATT MTU is the maximum size of the ATT packet contained in an L2CAP packet.
Given a maximum LL Data PDU length of 251 B, the maximum size of the L2CAP packet is 251
B, with 4 of those bytes being headers, meaning that the maximum size of the ATT MTU is
251 B - 4 B = 247 B.

## Traffic calculations

Given a bit rate of 2 Mbps and a connection interval of 10 ms with
frequencies of 4 kHz for the EMG, 100 Hz for the IMU, and 1 kHz for
the piezo, these calculations show the viability of sending the sensor
data as notifications for each period over BLE. The sensor data gets
encapsulated in multiple headers before being sent over BLE. First an
ATT header of 3 B is added
[[Table 3.38, Vol 3, Part F]](https://www.bluetooth.com/specifications/specs/core-specification-5-4/).
This is followed by an L2CAP header of 4 B
[[Figure 3.1, Vol 3, Part A]](https://www.bluetooth.com/specifications/specs/core-specification-5-4/),
an LL Data PDU header of 2 B
[[Figure 2.24, Vol 6, Part B]](https://www.bluetooth.com/specifications/specs/core-specification-5-4/),
and finally an LL packet header of 9 B
[[Figure 2.1, Vol 6, Part B]](https://www.bluetooth.com/specifications/specs/core-specification-5-4/)
for a total of 18 extra bytes.

The sizes of the different packets are shown in the table below:

| Data | Size |
| ---- | ---- |
| EMG data + metadata size per packet | 80 B + 4 B = 84 B |
| Encapsulated as EMG LL packet | 84 B + 18 B = 102 B. |
| IMU data + metadata size per packet | 24 B + 4 B = 28 B. |
| Encapsulated as IMU LL packet | 28 B + 18 B = 46 B. |
| Piezo data + metadata size per packet | 20 B + 4 B = 24 B. |
| Encapsulated as piezo LL packet | 24 B + 18 B = 42 B. |
| Empty packet size (LL Data PDU + LL packet headers) | 2 B + 9 B = 11 B. |

Since all values are below 251 B, they fit within a single LL packet each. The
transmission delay of each individual packet is shown in the table below:

| Data | Transmission delay |
| --- | -- |
| EMG | 102 B / 2 Mbps = 408 &mu;s |
| IMU | 46 B / 2 Mbps = 184 &mu;s |
| Piezo | 42 B / 2 Mbps = 168 &mu;s |
| Empty packet | 11 B / 2 Mbps = 44 &mu;s |
| Inter-frame spacing | 150 &mu;s [[4.1.1, Vol 6, Part B]](https://www.bluetooth.com/specifications/specs/core-specification-5-4/) |

Assuming a normal connection event when the Central is subscribed to
notifications for all sensors, the Central will send empty packets and
the Peripheral will send EMG, IMU, and piezo data packets. An example of a
full transmission sequence of packets during the connection event is then:

`EMPTY + IFS + EMG + IFS + EMPTY + IFS + IMU + IFS + EMPTY + IFS + PIEZO + IFS + EMPTY`

The time it takes to send all packets in the connection event is then:

$$
4 \cdot 44\ \mu\text{s} + 6 \cdot 150\ \mu\text{s} + 408\ \mu\text{s} + 184\ \mu\text{s} + 168\ \mu\text{s} = 1.836\ \text{ms}
$$

1.836 ms is well within the deadline of 10 ms, so the amount of data
being sent should not be a problem.

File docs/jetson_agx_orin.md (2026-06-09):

# NVIDIA Jetson AGX Orin Developer Kit
The device used for coordinating and controlling the rest of the system is an
[NVIDIA Jetson AGX Orin Developer Kit](https://www.nvidia.com/en-us/autonomous-machines/embedded-systems/jetson-orin/).

## Connecting to the Orin
You can access the Orin either by connecting it to a keyboard, mouse, and monitor, or by connecting to it using `ssh`.

### Connecting via ssh
You can use the USB-C port next to the 40-pin header to
[connect to the Orin using a virtual ethernet connection](https://docs.nvidia.com/jetson/agx-orin-devkit/user-guide/howto.html#up-stream-facing-port-ufp).
The location of the USB-C port is shown in the image below, with a white USB cable connected to it:

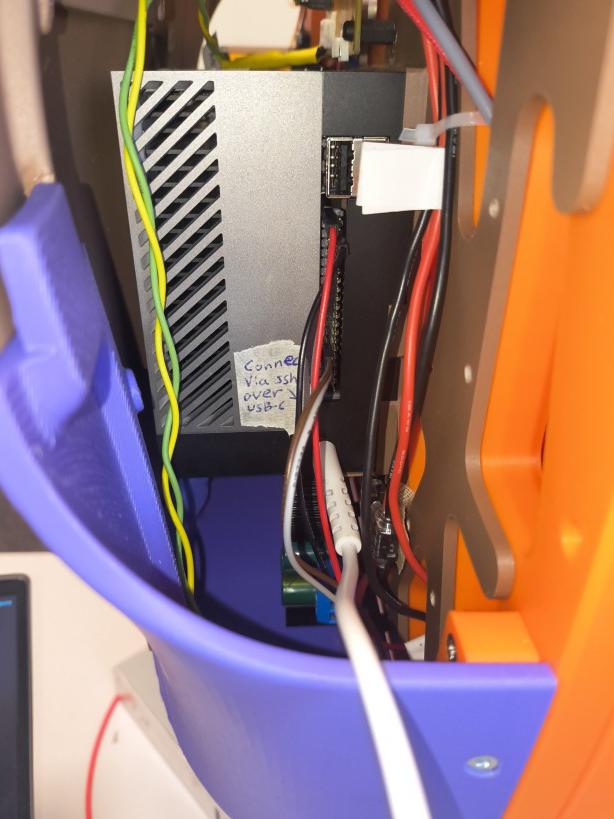
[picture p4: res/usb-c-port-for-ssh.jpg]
An image showing the USB-C port on the NVIDIA Jetson AGX Orin in the bionic arm's torso


The Orin will be given the IP address 192.168.55.1 and your computer will be given the address 192.168.55.100.
You should then be able to `ssh` into the Orin using `ssh bigboyorin@192.168.55.1` and entering its password.

Connecting the Orin to your computer using the USB-C port next to the 40-pin header also makes the
Orin show up as a storage device that contains, among other things, some readme files regarding
setting up the Orin. If you require more information, that is one place to check.

> [!important]
> When trying to connect to the Orin via SSH from computers running Windows, we've gotten disconnected quickly
> after connecting with the error message `client_loop: send disconnect: Connection reset`.
> If you run into the same problem, try connecting via macOS or Linux if possible.

## Running python
The Orin uses an old version of Ubuntu without access to newer python versions. See [src/README.md](/src/README.md#python-on-the-agx-orin) for more information.

## Connecting the Orin to a CAN bus
The Orin has two CAN controllers built-in, but no CAN transceivers.
Once the CAN transceiver has been connected to the correct pins in the
[40-pin header](https://developer.nvidia.com/downloads/assets/embedded/secure/jetson/agx_orin/jetson_agx_orin_devkit_carrier_board_specification_sp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),
the correct registers have to be written to, CAN kernel drivers have to be enabled,
and a virtual CAN interface has to be created. This process is taken care of by the
[scripts/agx_setup_can.sh](/scripts/agx_setup_can.sh) script, creating the `can0`
interface for the CAN0 pins and the `can1` interface for the CAN1 pins.

More information regarding setting up and using CAN on the Orin can be found in the
[NVIDIA Jetson Linux Developer Guide](https://docs.nvidia.com/jetson/archives/r36.4.3/DeveloperGuide/HR/ControllerAreaNetworkCan.html).

## Connecting to the internet
The Orin has an Ethernet port that can be used to connect it to the internet. It also has Wi-Fi
functionality, but it doesn't support WPA2-Enterprise which is what eduroam uses to secure the connection,
meaning you'll have to find some other way to connect it over Wi-Fi (such as a mobile hotspot).

## More info
You can find more information in the
[NVIDIA Jetson AGX Orin Developer Kit Carrier Specification](https://developer.nvidia.com/downloads/assets/embedded/secure/jetson/agx_orin/jetson_agx_orin_devkit_carrier_board_specification_sp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)
and the [NVIDIA Jetson AGX Orin Developer Kit User Guide](https://developer.nvidia.com/embedded/learn/jetson-agx-orin-devkit-user-guide/index.html).

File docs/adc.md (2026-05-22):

# ADC on the ESP32-C3-Zero

The way the ADC works on the ESP32-C3-Zero is that the voltage
$V_\text{in}$ fed to the ADC is linearly interpolated from the
range $`\left[0, V_\text{ref}\right]`$ onto the range
$`\left[0, 2^\text{bitwidth} - 1\right]`$, where $V_\text{ref}$ is the ADC's
internal reference voltage and bitwidth determines the value that is returned from the ADC
when $V_\text{in} = V_\text{ref}$. The equation governing this linear interpolation
is shown
[in the documentation](https://docs.espressif.com/projects/esp-idf/en/v6.0.1/esp32c3/api-reference/peripherals/adc/index.html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),
with $V_\text{data}$ representing $V_\text{in}$.

$V_\text{ref}$ is designed to be $1.1 \mathrm{V}$ for the ESP32-C3-Zero, meaning that the maximum voltage that can be measured using the ADC
is $1.1 \mathrm{V}$. However, the ADC can be configured to extend the input voltage range by setting an attenuation level.
The maximum voltage that can be read is then increased by dividing $V_\text{ref}$ by a coefficient $k$ corresponding
to the selected attenuation level. Using the maximum attenuation level of $12\ \text{dB}$,
$k \approx 0.25$ ([from the Technical Reference Manual](https://documentation.espressif.com/esp32-c3_technical_reference_manual_en.pdf#subsubsection.34.2.3.2)),
meaning that the maximum voltage that can be read is $V_\text{ref} / 0.25 = 1.1 \mathrm{V} / 0.25 = 4.4 \mathrm{V}$.

However, although the ADC can measure voltages up to $4.4 \mathrm{V}$, values at
the ends of the measurement range do not map onto the voltage linearly. As such, the
effective measurement range that stays linear for an attenuation level
of $12\ \text{dB}$ is about $`\left[0, 2.5\right] \mathrm{V}`$
([Table 5-6 in the C3's datasheet](https://documentation.espressif.com/esp32-c3_datasheet_en.pdf#subsection.5.5)).

To get the best results from the ADC measurements, we then want to make sure that any voltage passed to
the ADC is below $2.5 \mathrm{V}$. For the sensors that provide voltages up to $3.3 \mathrm{V}$, we use voltage dividers
with $R_1 = 1\ \text{k}\Omega$ and $R_2 = 2\ \text{k}\Omega$ such that the voltage is stepped down to

$$
V_\text{out} = 3.3 \mathrm{V} \times \frac{2\ \text{k}\Omega}{1\ \text{k}\Omega + 2\ \text{k}\Omega} = 2.2 \mathrm{V}.
$$

## Calibration
Although the reference voltage is designed to be $1.1 \mathrm{V}$, it might vary slightly between chips. To compensate for this, we use
the [calibration driver](https://docs.espressif.com/projects/esp-idf/en/v5.5.4/esp32c3/api-reference/peripherals/adc_calibration.html)
provided by ESP-IDF to get more accurate ADC readings.

## More information
More infomation can be found in
[the datasheet](https://documentation.espressif.com/esp32-c3_datasheet_en.pdf#subsection.5.5),
[the Technical Reference Manual](https://documentation.espressif.com/esp32-c3_technical_reference_manual_en.pdf#subsubsection.34.2.3.2),
and
[the documentation](https://docs.espressif.com/projects/esp-idf/en/v6.0.1/esp32c3/api-reference/peripherals/adc/index.html).

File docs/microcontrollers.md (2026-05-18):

# Microcontrollers used in the LIMB project

The microcontrollers used in this project are [ESP32-C3-Zeros](https://www.waveshare.com/esp32-c3-zero.htm).
There are 5 of them used in total, 4 for the robot arm and 1 for the cuff on the human arm.

The ones on the robot arm communicate with the NVIDIA Jetson AGX Orin using a CAN bus. They
send potentiometer, pressure, and IMU data to the Orin and receive motor actuation commands from it.
For more information regarding the CAN bus, look in [docs/can/can.md](./can.md).

The one on the human arm communicates with the Orin using Bluetooth Low Energy. It collects
data from the EMG, IMU, and Piezo sensors and sends the data as notifications that the Orin
subscribes to. For more inforamation regarding the use of BLE, look in [docs/bluetooth_low_energy.md](./ble.md).

The programs for the microcontrollers can be found in the [src/esp32/](../src/esp32/) directory.

## [ESP32-C3-Zero](https://www.waveshare.com/esp32-c3-zero.htm)

The pinout for the ESP32-C3-Zero is shown in the following image:

ESP32-C3-Zero pinout image

More information can be found in its [datasheet](https://documentation.espressif.com/esp32-c3_datasheet_en.pdf)
and [technical reference manual](https://documentation.espressif.com/esp32-c3_technical_reference_manual_en.pdf).

> [!warning]
> The ESP32-C3-Zero have some pins that can be used to affect the boot procedure called
> [strapping pins](https://documentation.espressif.com/esp32-c3_datasheet_en.pdf#section.3).
> The way this is achieved is by changing the voltage level provided to the pins during the
> boot sequence. It can also be the case that they output some signal on the pin during
> the flashing process. This output signal could affect the thing connected to the pin, e.g.
> a servo that interprets the signal as a pulse width and starts moving (this has happened
> to us and is an issue since we've
> [modded the servos to be continuous](./servo_modification.md)).
> As such, it is best to avoid using them if possible, or otherwise make sure that
> they are used in a safe way.
>
> Other pins to be wary of are
> [the GPIO18 and GPIO19 pins which are used for USB serial communication](https://documentation.espressif.com/esp32-c3_datasheet_en.pdf#subsubsection.2.3.4)
> and
> [the GPIO20 and GPIO 21 pins which are used for UART communication](https://documentation.espressif.com/esp32-c3_datasheet_en.pdf#subsubsection.2.3.4).
> These allow you to interface with the ESP32-C3-Zero via a USB cable (e.g. flashing or monitoring
> output), which means they should also ideally be avoided.

## [ESP-IDF](https://github.com/espressif/esp-idf)
ESP-IDF is the official development framework used for ESP32. This project has been
developed using version 5.5.1, for which the docs can be found
[here](https://docs.espressif.com/projects/esp-idf/en/v5.5.1/esp32c3/index.html).

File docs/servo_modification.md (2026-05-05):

# Modifying the JX Servo PDI-HV2060MG Servos to provide continuous rotation

The shoulder flexion/extension and abduction/adduction
joints of the robotic arm are moved using [JX Servo
PDI-HV2060MG](http://www.jx-servo.com/en/Product/STANDARD/SD/544.html)
servo motors. These servos have a maximum range of motion of 180&deg;,
probably corresponding to pulse widths in the range 650&ndash;2350 &mu;s,
(there's literally no official datasheet available, so it's hard to
state things confidently). This limited range of motion ends up being a
problem in this project since both joints controlled by the servos have
a gear ratio of 15:1 meaning that the effective range we get for those
joints is 12&deg;.

## Modding servo motors to be continuous

To address the conundrum of the servo motors not
having a large enough range of motion, we followed [this
guide](https://learn.adafruit.com/modifying-servos-for-continuous-rotation/overview)
to modify them so that they provide continuous rotation, allowing us
to rotate the joints as much as we want (the guide is for a different
servo motor, but they work the same way). The basic idea is:
1. Remove the internal potentiometer.
2. Remove the physical stop on the gears.
3. Add resistors between $V_{\text{in}}$ and $V_{\text{out}}$ as well
   as $V_{\text{out}}$ and $\text{gnd}$ where the internal
   potentiometer was connected.

## Crash course in how the unmodded servo works

The servo has an internal potentiometer detecting its current
position. Providing the servo with a pulse width makes the servo target
a value of the potentiometer, thereby making it rotate until it reaches
the correct value. The range of pulse widths that correspond with the
180&deg; range of motion is (probably?) 650&ndash;2350 &mu;s, with ~1500 &mu;s
being the midpoint.

## Controlling the modded servo motors

The way the HV2060 servo motors function after the modification is that
the servo thinks that its internal potentiometer is always positioned at
its midpoint corresponding to a pulse width of ~1500 &mu;s. If it
is then given a pulse width other than 1500 &mu;s it will start
rotating in an attempt to reach its corresponding target potentiometer
value. However, since we make the servo think its potentiometer value
is always at its midpoint, the servo ends up rotating continuously since
it never reaches its target potentiometer value.

The direction of the rotation is controlled by setting the pulse width
either greater than or less than the midpoint of 1500 &mu;s,
while setting the pulse width to exactly 1500 &mu;s makes it stop
rotating. The greater the absolute difference between the pulse width used
and the midpoint, the greater the resulting speed and torque ends up being.

### Issues with controlling the modified servo
> [!caution]
> One consequence of this modification is that the software is entirely
> responsible for making sure that the motors perform as desired. If
> the software sets a pulse width other than 1500 &mu;s, the
> motor *will* keep on rotating until it receives a new pulse width of
> 1500 &mu;s. That means that if the motors are rotating and the
> microcontroller's program is unable to update the pulse width once the
> joint reaches its desired angle (e.g. due to a crash, infinite loop,
> or simply a missed deadline), the joint will keep on rotating past its
> desired angle, possibly past its safety limits, and potentially breaking
> the arm.

The speed that the servo rotates at is not linear with relation to the
pulse width's distance from the midpoint. The midpoint has an effective
deadband around it where the motor won't rotate. Once the pulse width
distance from the midpoint is large enough, the motor starts rotating,
but with a decently high angular velocity right from the start, making
it difficult to perform small adjustments to the joint angles. The
velocity and torque then increases together with the pulse width until
it eventually caps out long before the maximum pulse width is reached.

Another thing that affects the speed of the servo is its load. This
means that a pulse width rotating in a direction which raises the arm
will raise the arm slower than the equivalent pulse width rotating in
a direction that lowers the arm, since the motor has to fight against-
or is helped by gravity. This also means that the effective pulse
width deadband around the midpoint is larger in the direction that
experiences greater load, since more torque is required to overcome it.
Whether the pulse width that maxes out the speed without load will still
apply maximum torque under load has not been investigated, but seems to
not be necessary for the loads that the robot arm experiences.

All of these issues result in a situation where the servo *can* move
the arm, but it is difficult to move it precisely. The actual velocity
is unlikely to be the same as the predicted velocity, meaning that
motor ramping algorithms are likely to make the joint overshoot its
target angle.

## Servo component
To make controlling the servo motor
relatively painless, an ESP-IDF component was created in
[`src/esp32/components/servo/`](../src/esp32/components/servo/). See its
[readme](../src/esp32/components/servo/readme.md) for more information.

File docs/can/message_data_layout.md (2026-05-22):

# CAN Message data layouts
This document shows the basic data layout for the different types of
CAN messages. An x in the byte representation means the byte is unused.

## Motor stops
Motor stops don't send any data, just receiving the message is the
indication to immediately stop the motor.

## Motor actuations
Little endian 4-byte float angle and little endian 4-byte float velocity.

### Byte representation of CAN message data field (8 bytes)
| byte  |  0 | 1 | 2 |  3 | 4 | 5 | 6 | 7 |
| ----- | -- | --- | --- | -- | - | - | - | - |
| value | ang lo | ang mid lo | ang mid hi | ang hi | vel lo | vel mid lo | vel mid hi | vel hi |

## Potentiometers
Little endian 4-byte float angle.

### Byte representation of CAN message data field (8 bytes)
| byte  |  0 | 1 | 2 |  3 | 4 | 5 | 6 | 7 |
| ----- | -- | --- | --- | -- | - | - | - | - |
| value | lo | mid lo | mid hi | hi | x | x | x | x |

## Pressure sensors
Little endian 2-byte integer value representing millivolts.

### Byte representation of CAN message data field (8 bytes)
| byte  |  0 |  1 | 2 | 3 | 4 | 5 | 6 | 7 |
| ----- | -- | -- | - | - | - | - | - | - |
| value | lo | hi | x | x | x | x | x | x |

## IMUs
6 Little endian 4-byte float values.

The IMU samples consist of two triplets: (pitch, roll, yaw) for the gyro and (x, y, z)
for the accelerometer. Each value in a triplet is a 4-byte floating point value,
meaning we have 12 bytes per triplet for a total of 24 bytes. Since a
CAN message is limited to 8 bytes of data, we have to split the samples into multiple
messages. For simplicity's sake, we're letting each of the six floating point values be its own
CAN message.

### Byte representation of CAN message data field (8 bytes)
| byte  | 0 | 1 | 2 | 3 | 4 | 5 | 6 | 7 |
| ----- | --- | --- | --- | --- | ---- | ---- | - | - |
| value | float lo | float mid lo | float mid hi | float hi | x | x | x | x |

## Intelligent gripper commands

Single byte representing a boolean value for if the hand should be in its intelligent grip state or not.

### Byte representation of CAN message data field (8 bytes)
| byte  | 0 | 1  | 2  | 3 | 4 | 5 | 6 | 7 |
| - | - | -  | -  | - | - | - | - | - |
| value | bool | x  | x  | x | x | x | x | x |

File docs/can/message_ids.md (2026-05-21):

# CAN message IDs and their rationale
This document describes which CAN messages are used in the system and what their IDs are.
It also goes into some more detail regarding the decisions behind the prioritization
of the messages along with calculations showing the feasibility of the network
with regards to potential message latency.

## CAN message ID allocation strategy
We want to allow for easy filtering of relevant messages. We also want to
prioritize different types of messages. By splitting up the 11 ID bits into
three sections representing the message type, the recipient node, and a generic ID
we're able to both prioritize and easily filter the messages.

The layout we use is the following, with $x$ belonging to the message type section,
$y$ belonging to the recipient section, and $z$ belonging to the generic section:
| Bit | 10  | 9 | 8 | 7 | 6 | 5 | 4 | 3 | 2 | 1 | 0 |
|---|-----|-----|-----|-----|-----|-----|-----|-----|-----|-----|-----|
| Section | $x$ | $x$ | $x$ | $y$ | $y$ | $y$ | $z$ | $z$ | $z$ | $z$ | $z$ |

For the message types, we get the following masks:

| Message type  | Binary value | Hexadecimal value |
|---|---|---|
| Stop | $\texttt{001\ XXXX\ XXXX}$ | $\texttt{0x1XX}$  |
| Actuation | $\texttt{010\ XXXX\ XXXX}$ | $\texttt{0x2XX}$  |
| Potentiometer | $\texttt{100\ XXXX\ XXXX}$ | $\texttt{0x4XX}$  |
| IMU | $\texttt{101\ XXXX\ XXXX}$ | $\texttt{0x5XX}$  |
| Pressure | $\texttt{111\ XXXX\ XXXX}$ | $\texttt{0x7XX}$  |

For the recipients, we get the following masks:

| Node | Binary value | Hexadecimal value |
|---|---|---|
| Robot shoulder | $\texttt{XXX\ 001X\ XXXX}$ | $\texttt{0xX2X}$  |
| Robot elbow | $\texttt{XXX\ 010X\ XXXX}$ | $\texttt{0xX4X}$  |
| Robot wrist | $\texttt{XXX\ 011X\ XXXX}$ | $\texttt{0xX6X}$  |
| Robot hand | $\texttt{XXX\ 100X\ XXXX}$ | $\texttt{0xX8X}$  |
| Robot AGX Orin | $\texttt{XXX\ 101X\ XXXX}$ | $\texttt{0xXAX}$  |

This way we prioritize stop messages and actuation messages the most. We also
prioritize messages intended for the robot shoulder and robot elbows the most,
since they are the strongest motors and could cause the most damage if their
current movement target is not up to date.

## Robot messages
These are the messages that are send over the robot arm's CAN bus.

### Stop messages
| CAN ID | Message |
| --- | ---  |
| $\texttt{0x120}$ | Shoulder up/down servo stop |
| $\texttt{0x121}$ | Shoulder left/right servo stop  |
| $\texttt{0x122}$ | Upper arm rotation stepper stop |
| $\texttt{0x140}$ | Elbow up/down stepper stop |
| $\texttt{0x160}$ | Lower arm rotation servo stop |
| $\texttt{0x161}$ | Finger servos stop |
| $\texttt{0x162}$ | Thumb servo stop |
| $\texttt{0x163}$ | Index servo stop |
| $\texttt{0x164}$ | Middle servo stop |
| $\texttt{0x165}$ | Ring servo stop |
| $\texttt{0x166}$ | Pinky servo stop |

### Actuation messages
| CAN ID | Message |
| --- | --- |
| $\texttt{0x220}$ | Shoulder up/down servo actuation |
| $\texttt{0x221}$ | Shoulder left/right servo actuation  |
| $\texttt{0x222}$ | Upper arm rotation stepper actuation |
| $\texttt{0x240}$ | Elbow up/down stepper actuation |
| $\texttt{0x260}$ | Lower arm rotation servo actuation |
| $\texttt{0x261}$ | Thumb servo actuation |
| $\texttt{0x262}$ | Index servo actuation |
| $\texttt{0x263}$ | Middle servo actuation |
| $\texttt{0x264}$ | Ring servo actuation |
| $\texttt{0x265}$ | Pinky servo actuation |
| $\texttt{0x266}$ | Hand set grip state |

### Potentiometer messages

| CAN ID | Message |
| --- | --- |
| $\texttt{0x4A0}$  | Elbow up/down stepper potentiometer |
| $\texttt{0x4A1}$  | Upper arm rotation stepper potentiometer |
| $\texttt{0x4A2}$  | Shoulder up/down servo potentiometer |
| $\texttt{0x4A3}$  | Shoulder left/right servo potentiometer  |

### IMU messages
| CAN ID | Message |
| --- | --- |
| $\texttt{0x5A0}$  | IMU robot upper arm gyro pitch |
| $\texttt{0x5A1}$  | IMU robot upper arm gyro roll |
| $\texttt{0x5A2}$  | IMU robot upper arm gyro yaw |
| $\texttt{0x5A3}$  | IMU robot upper arm acceleration x |
| $\texttt{0x5A4}$  | IMU robot upper arm acceleration y |
| $\texttt{0x5A5}$  | IMU robot upper arm acceleration z |
| $\texttt{0x5A6}$  | IMU robot lower arm gyro pitch |
| $\texttt{0x5A7}$  | IMU robot lower arm gyro roll |
| $\texttt{0x5A8}$  | IMU robot lower arm gyro yaw |
| $\texttt{0x5A9}$  | IMU robot lower arm acceleration x |
| $\texttt{0x5AA}$  | IMU robot lower arm acceleration y |
| $\texttt{0x5AB}$  | IMU robot lower arm acceleration z |
| $\texttt{0x5AC}$  | IMU robot hand gyro pitch |
| $\texttt{0x5AD}$  | IMU robot hand gyro roll |
| $\texttt{0x5AE}$  | IMU robot hand gyro yaw |
| $\texttt{0x5AF}$  | IMU robot hand acceleration x |
| $\texttt{0x5B0}$  | IMU robot hand acceleration y |
| $\texttt{0x5B1}$  | IMU robot hand acceleration z |

### Pressure messages
| CAN ID | Message |
| --- | --- |
| $\texttt{0x7A0}$  | Thumb pressure sensor |
| $\texttt{0x7A1}$  | Index pressure sensor |
| $\texttt{0x7A2}$  | Middle pressure sensor |
| $\texttt{0x7A3}$  | Ring pressure sensor |
| $\texttt{0x7A4}$  | Pinky pressure sensor |

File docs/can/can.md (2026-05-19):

# CAN

A CAN bus is used to allow the NVIDIA Jetson AGX Orin to communicate with the ESP32-C3-Zeros
distributed on the robot arm.

## CAN version
The CAN version used for this project is CAN 2.0, meaning only classical
frames supporting up to 8 bytes of data per message are used. This is
a hard limit since the ESP32-C3-Zeros used in the project
[don't support FD or XL frames](https://docs.espressif.com/projects/esp-idf/en/v5.4.4/esp32c3/api-reference/peripherals/twai.html#overview).
Regarding the CAN IDs, standard frames allowing for 11-bit IDs are used
instead of extended frames allowing for 29-bit IDs. However, this is
not a hard limit and could be changed in the future if necessary.

## CAN bus connections
The CAN bus is composed of a twisted pair running along the arm.
The Orin and all ESP32-C3-Zeros are connected to the CAN bus using
SN65HVD232D CAN transceivers ([datasheet](https://www.ti.com/lit/gpn/sn65hvd232)),
with the transceivers at both ends of the bus containing 120&Omega; terminating resistors.

## CAN bitrate
Since the CAN bus is on the order of 1 meter, we're able to use
a bitrate of 1 Mbit/s
([Source, see Table 1](https://www.ti.com/lit/an/slla270/slla270.pdf)).

## Using CAN with the NVIDIA Jetson AGX Orin Developer Kit

See [docs/jetson_agx_orin.md](../jetson_agx_orin.md) for information
regarding connecting the Orin to a CAN bus.

## Using CAN with the ESP32-C3-Zero

The ESP32-C3-Zeros support something called Two-Wire Automotive Interface (TWAI),
which is compatible with CAN frames, so it's basically CAN by another name. The
[TWAI driver](https://docs.espressif.com/projects/esp-idf/en/v5.4.4/esp32/api-reference/peripherals/twai.html)
in ESP-IDF is used to create the component in
[src/esp32/components/can_driver/](../../src/esp32/components/can_driver/) which
we use to send and receive messages over the CAN bus.

> [!note]
> The ESP-IDF TWAI driver used is from ESP-IDF v5.4.4, not the updated one from v5.5.1.

## Controlling the robot arm using CAN
Each joint connected to a motor can be controlled by sending
actuation CAN messages over the CAN bus. An overview
of the CAN message IDs used and their data layout can be
found in [docs/can/message_ids.md](./message_ids.md) and
[docs/can/message_data_layout.md](./message_data_layout.md).
In case the documentation ends up out of date, the definitions for the
message IDs in the codebase are in
[src/esp32/components/can_driver/include/can_driver.h](../../src/esp32/components/can_driver/include/can_driver.h)
and the data layout is defined by where the CAN messages are received
in the relevant module in [src/esp32/](../../src/esp32/).

In practice, the way you will end up sending the CAN messages is from
the Orin. Once you've set up the CAN network interface on the Orin
([there's a script you can run](../../scripts/agx_setup_can.sh)),
you can send CAN messages over the bus using the interface.

As an example, the elbow joint is controlled by sending a CAN
message with the ID 0x240 with the data being a little endian float
value for the angle in degrees followed by another little endian
float value for the angular velocity in degrees per second. The
limits for the supported angles and velocity can be found in the
configuration structs used when initializing the stepper motor in
[src/esp32/robot_elbow_module/](../../src/esp32/robot_elbow_module/).
As long as the configuration is correct, the received angles and velocities
should be clamped to the supported limits, meaning that if you send an angle
of 60&deg; to a motor that is configured to only allow a maximum of 50&deg;,
the angle targeted will be 50&deg;.

Here is a simple example python program using
[python-can](https://github.com/hardbyte/python-can) that sends an
actuation CAN message to the elbow stepper:
```python
import struct

import can

# Open a connection to the CAN interface.
# NOTE: Make sure the bitrate is the same as the other microcontrollers
# connected to the CAN bus use (1 Mbit/s in our case).
with can.Bus(interface='socketcan', channel='can0', bitrate=1_000_000) as bus:
    ELBOW_ACTUATION_CAN_ID = 0x240
    elbow_angle_deg = 40.0
    elbow_velocity_dps = 20.0
    # Making sure that the floats are packed in 8 bytes in little endian byte order.
    can_message_data = struct.pack('<ff', elbow_angle_deg, elbow_velocity_dps)
    msg = can.Message(
        arbitration_id=ELBOW_ACTUATION_CAN_ID,
        data=can_message_data,
        is_extended_id=False,
    )

    try:
        bus.send(msg)
        print("Successfully sent message on the CAN bus")
    except can.CanError as e:
        print(f"Some error occurred: {e}")
```

## Receiving CAN messages from the robot arm
There are various sensors on the robot arm that you might want to use. These can be received
on the Orin in a similar fashion to how actuation messages are sent in the previous section.
The possible CAN message IDs are in [docs/can/message_ids.md](./message_ids.md) and their
data layouts are in [docs/can/message_data_layout.md](./message_data_layout.md).

Here is a simple example python program using
[python-can](https://github.com/hardbyte/python-can) that reads the
elbow joint's current angle from a potentiometer CAN message.
```python
import struct

import can

# Open a connection to the CAN interface.
# NOTE: Make sure the bitrate is the same as the other microcontrollers
# connected to the CAN bus use (1 Mbit/s in our case).
with can.Bus(interface='socketcan', channel='can0', bitrate=1_000_000) as bus:
    try:
        msg = bus.recv()
        ELBOW_POTENTIOMETER_CAN_ID = 0x4A0
        if msg.arbitration_id == ELBOW_POTENTIOMETER_CAN_ID:
            # There's a trailing comma since unpack returns a tuple even though
            # it's only one value,
            elbow_angle, = struct.unpack('<f', msg.data)
            print(f"Successfully received angle {elbow_angle} degrees on the CAN bus")
    except can.CanError as e:
        print(f"Some error occurred: {e}")
```

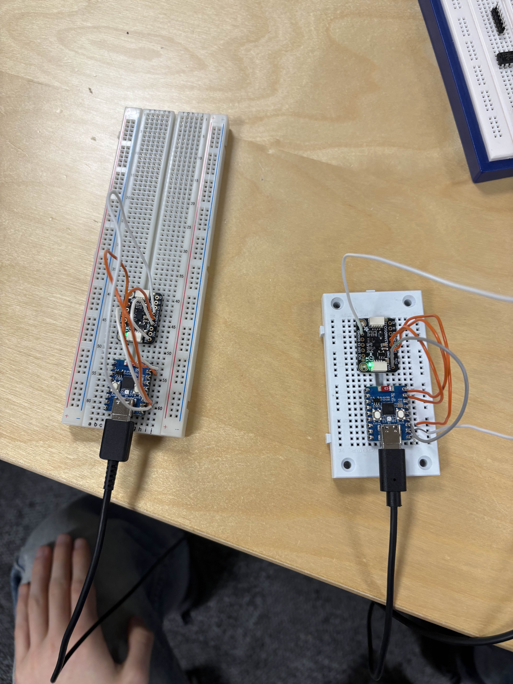
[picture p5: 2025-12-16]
LIMB Simulation/cable_management_illustrations/firstpic.jpg

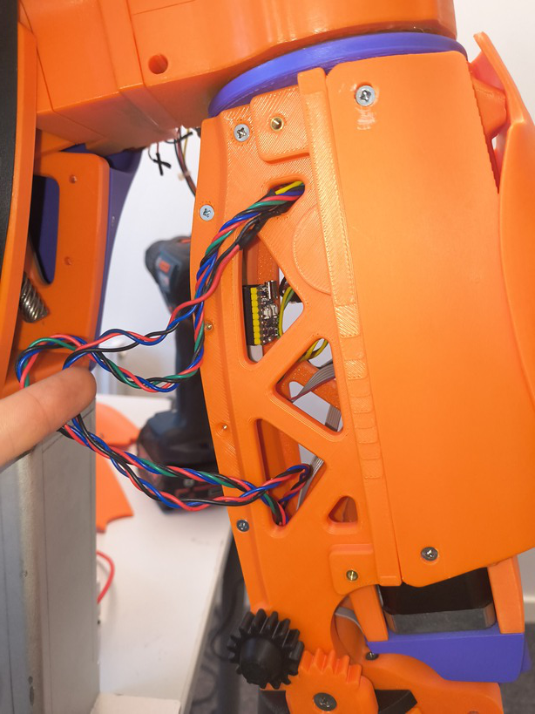
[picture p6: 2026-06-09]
res/hand_motor_module.jpg

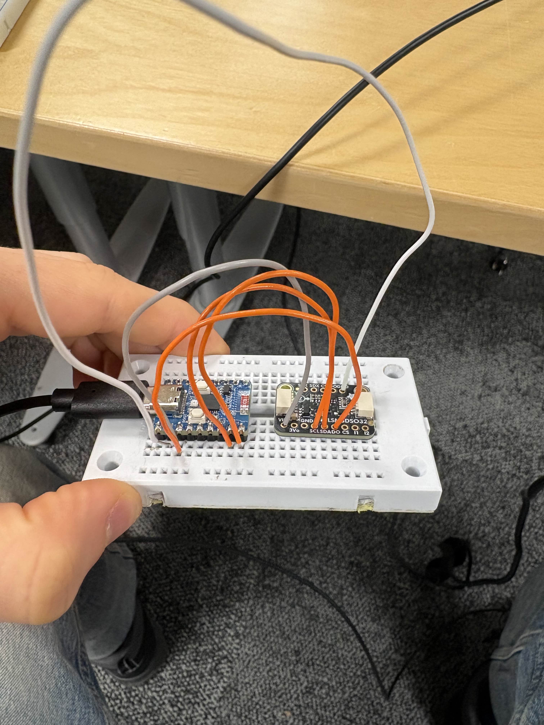
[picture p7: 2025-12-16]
LIMB Simulation/cable_management_illustrations/secondpic.jpg

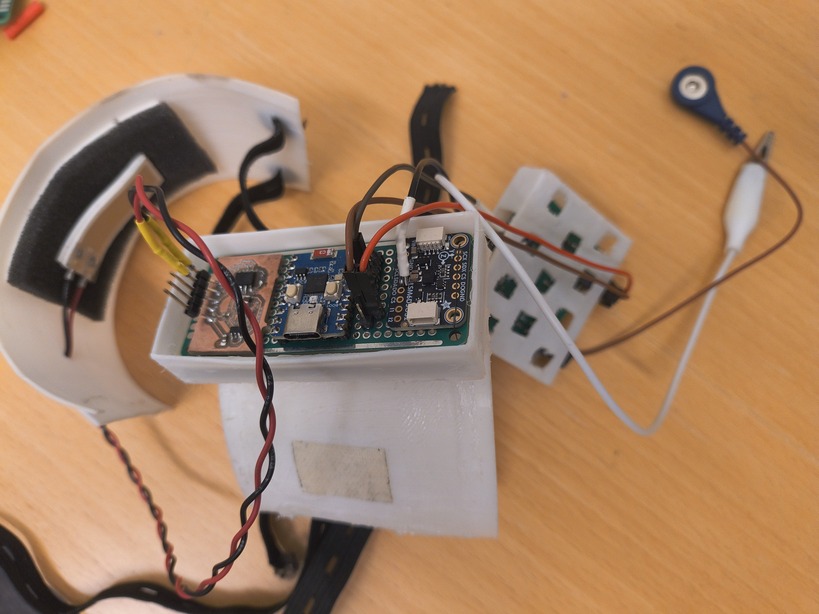
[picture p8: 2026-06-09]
res/human_lower_arm_module.jpg

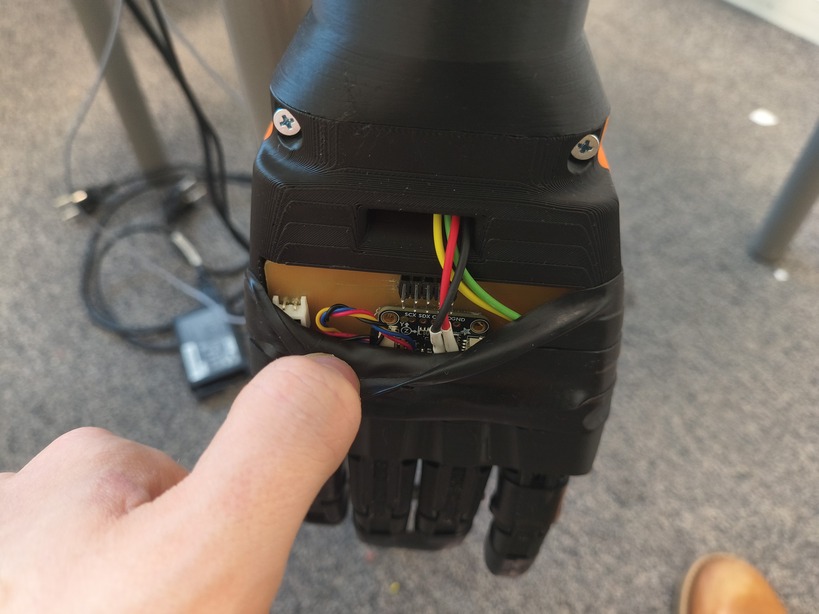
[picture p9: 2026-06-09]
res/hand_pressure_module.jpg

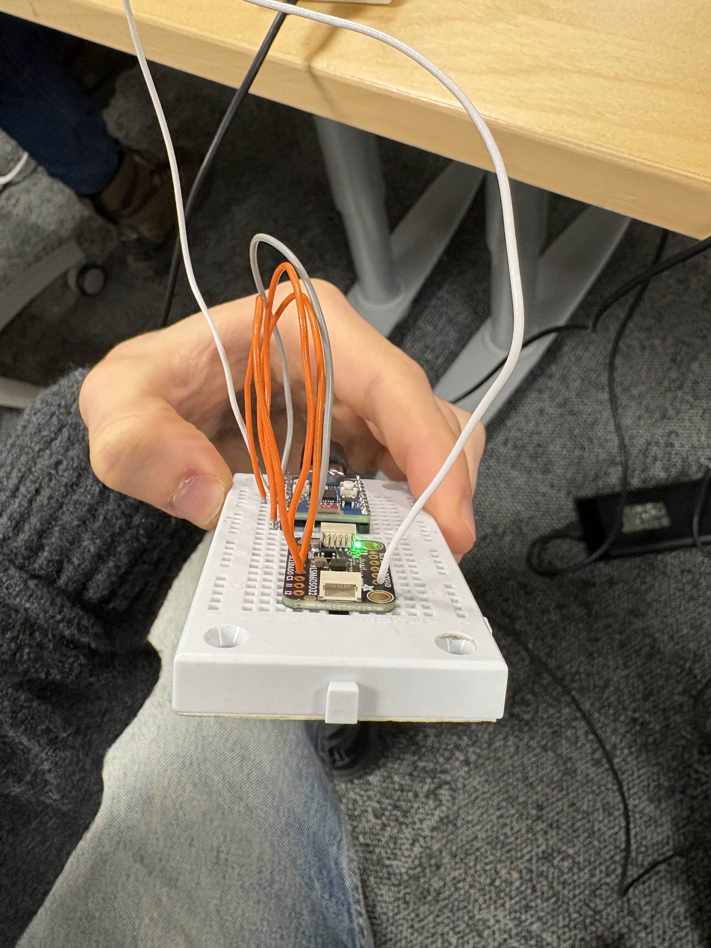
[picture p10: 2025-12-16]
LIMB Simulation/cable_management_illustrations/thirdpic.jpg

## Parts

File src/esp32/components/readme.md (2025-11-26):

# Components
This directory contains all the ESP-IDF components created for this project. As long as
you follow the directions in the `esp32` directory's readme regarding adding this `components`
directory to your app's `EXTRA_COMPONENT_DIRS`, you will have access to all the components
in this directory in your app.

## How to create and use components
At its core, a component is defined by a `CMakeLists.txt` file with the following contents:
```cmake
idf_component_register(
  SRCS # After this we declare all source files used by the component.
    src1.c
    src2.c
  INCLUDE_DIRS # After this we declare all directories containing public include files.
    include_directory
  REQUIRES # After this we declare all components used as dependencies by the component.
    component_name
)
```

More information about what arguments can be provided to `idf_component_register`
can be found [here](https://docs.espressif.com/projects/esp-idf/en/stable/esp32/api-guides/build-system.html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).

A typical directory structure can look something like this:
```
.
├── CMakeLists.txt
├── include
│   ├── gap.h
│   ├── limb_ble_periph.h
│   └── sensors_service.h
├── readme.md
└── src
    ├── gap.c
    ├── limb_ble_periph.c
    └── sensors_service.c
```
with `CMakeLists.txt` having the contents:
```cmake
idf_component_register(
  SRCS
    src/limb_ble_periph.c
    src/sensors_service.c
    src/gap.c
  REQUIRES
    bt
  PRIV_REQUIRES
    nvs_flash
    esp_driver_gpio
  INCLUDE_DIRS
    include
)
```

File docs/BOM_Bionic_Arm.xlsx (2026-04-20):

Component | Datasheet | Purchase site | Amount | Cost/Unit (Kr)
Hand
HS-422 servo | Datasheet (https://www.electrokit.com/upload/product/41002/41002565/hs422.pdf) | Electrokit (https://www.electrokit.com/hs-422-standard-servo-0.4nm) | 3 | 99
ESP32-C3-Zero | Datasheet (https://www.waveshare.com/wiki/ESP32-C3-Zero) | Electrokit (https://www.electrokit.com/utvecklingskort-esp32-c3) | 2 | 79
6DOF LSM6DSO32 IMU | Datasheet (https://www.electrokit.com/upload/product/41017/41017943/lsm6dsox-and-ism330dhc-6-dof-imu.pdf) | Electrokit (https://www.electrokit.com/rorelsegivare-6dof-lsm6dso32) | 2 | 215
Temperatursensor NTC | Datasheet (https://www.electrokit.com/upload/product/41015/41015732/41015732_-_Analog_Temperature_Sensor.pdf) | Electrokit (https://www.electrokit.com/temperatursensor-ntc) | 2 | 29
SN65HVD232D, CAN Transceiver | Datasheet (https://docs.rs-online.com/3aeb/A700000006666475.pdf) | RS (https://se.rs-online.com/web/p/can-interface-ics/1977506?gb=s) | 10 | 31.448
Tryckkänsligt motstånd 0.3 | Datasheet (https://www.electrokit.com/upload/product/41013/41013008/2010-10-26-DataSheet-FSR400-Layout2.pdf) | Electrokit (https://www.electrokit.com/tryckkansligt-motstand-0.3) | 3 | 129
Stiftlist 2.54mm 1x40p brytbar |  | Electrokit (https://www.electrokit.com/stiftlist-2.54mm-1x40p-brytbar) | 10 | 9.5
Optical Gaming Navigation Chip | Datasheet (https://d3s5r33r268y59.cloudfront.net/datasheets/9604/2017-05-07-18-19-11/PMS0058-PMW3360DM-T2QU-DS-R1.50-26092016._20161202173741.pdf) | Github (https://github.com/mrjohnk/PMW3360DM-T2QU)
Skruvplint 2.54mm 2-pol |  | Electrokit (https://www.electrokit.com/skruvplint-2.54mm-2-pol) | 25 | 5.6
Emergency Stop | Datasheet (https://docs.rs-online.com/f173/0900766b8166e4e7.pdf) | RS (https://se.rs-online.com/web/p/emergency-stop-push-buttons/1682629?gb=s) | 1 | 277
PCA82C251T | Datasheet (https://www.electrokit.com/upload/product/41015/41015078/PCA82C251.pdf) | Elektrokit (https://www.electrokit.com/pca82c251t/ym-so-8-can-bus-transceiver) | 8 | 39
Sub-Total |  |  |  | 2203.48
Arm
ESP32-C3-Zero | Datasheet (https://www.waveshare.com/wiki/ESP32-C3-Zero) | Electrokit (https://www.electrokit.com/utvecklingskort-esp32-c3) | 2 | 79
6DOF LSM6DSO32 IMU | Datasheet (https://www.electrokit.com/upload/product/41017/41017943/lsm6dsox-and-ism330dhc-6-dof-imu.pdf) | Electrokit (https://www.electrokit.com/rorelsegivare-6dof-lsm6dso32) | 3 | 215
Temperatursensor NTC | Datasheet (https://www.electrokit.com/upload/product/41015/41015732/41015732_-_Analog_Temperature_Sensor.pdf) | Electrokit (https://www.electrokit.com/temperatursensor-ntc) | 3 | 29
AX-12 | Datasheet (https://emanual.robotis.com/docs/en/dxl/ax/ax-12a/)
Stegmotor NEMA17 1.8° 0.45Nm | Datasheet (https://www.electrokit.com/upload/quick/ea/2d/5b25_41032662-tds.pdf) | Electrokit (https://www.electrokit.com/stegmotor-nema17-1.80.45nm) | 3 | 199
Stegmotordrivare DRV8825 | Datasheet (https://www.electrokit.com/upload/product/41016/41016255/drv8825.pdf) | Electrokit (https://www.electrokit.com/stegmotordrivare-drv8825) | 10 | 79
Stegmotor NEMA23 1.8° 3Nm | Datasheet (https://www.electrokit.com/upload/quick/e6/0c/2f07_41032667-tds.pdf) | Electrokit (https://www.electrokit.com/stegmotor-nema23-1.83nm) | 2 | 629
HV2060MG Digital-servo | Datasheet (https://servodatabase.com/servo/jx-servo/pdi-hv2060mg) | Elgiganten (https://www.elgiganten.se/product/sport-fritid/leksaker/radiostyrda-fordon-tillbehor/reservdelar-for-radiostyrda-fordon/amewi-standard-servo-hv2060mg-digital-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) | 2 | 790
Grön Kopplingskabel RK0.5 | Datasheet (https://www.electrokit.com/upload/quick/1f/be/9861_H05V-K.pdf) | Electrokit (https://www.electrokit.com/rk-0.5mm2-gron-/m) | 10 | 4.5
Gul Kopplingskabel RK0.5 | Datasheet (https://www.electrokit.com/upload/quick/1f/be/9861_H05V-K.pdf) | Electrokit (https://www.electrokit.com/rk-0.5mm2-gul-/m) | 10 | 4.5
Stranded Wire PVC Red | Datasheet (https://media.distrelec.com/Web/Downloads/_t/ds/050667-10_eng_tds.pdf) | Elfa (https://www.elfa.se/en/stranded-wire-pvc-60v-5mm-copper-red-rkub-10m-nemiq-050667-10/p/30387783?pos=5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) | 1 | 147
Stranded Wire PVC Black | Datasheet (https://media.distrelec.com/Web/Downloads/_t/ds/050660-10_eng_tds.pdf) | Elfa (https://www.elfa.se/en/stranded-wire-pvc-60v-5mm-copper-black-rkub-10m-nemiq-050660-10/p/30387779?pos=5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) | 1 | 147
Potentiometer | Datasheet (https://docs.rs-online.com/56b9/0900766b81584534.pdf) | RS-Components (https://se.rs-online.com/web/p/potentiometers/8427021?gb=s) | 6 | 82,21
DC-DC converter |  | Electrokit (https://www.electrokit.com/en/dc-dc-omvandlare-1.2-35v-8a) | 4 | 149
Sub-Total |  |  |  | 5115
Cuff
ESP32-C3-Zero | Datasheet (https://www.waveshare.com/wiki/ESP32-C3-Zero) | Elektrokit (https://www.electrokit.com/utvecklingskort-esp32-c3) | 3 | 79
6DOF LSM6DSO32 IMU | Datasheet (https://www.electrokit.com/upload/product/41017/41017943/lsm6dsox-and-ism330dhc-6-dof-imu.pdf) | Elektrokit (https://www.electrokit.com/rorelsegivare-6dof-lsm6dso32) | 3 | 215
Connectivity Vibration Sensor | Datasheet (https://docs.rs-online.com/4380/0900766b8142cdd4.pdf) | RS (https://se.rs-online.com/web/p/vibration-sensors/8937177?gb=s) | 1 | 121.7
Sub-Total |  |  |  | 1003.7
HARLEY
Kullager 10x15x4 (SKF 61700) |  | https://www.kullagergrossisten.se/product/10x15x4-gummi-metalltat--avid | 8 | 15 | Är inte helt hundra om jag inte kommer använda fler lager, så kanske ta 2 extra av varje? (de två första)
Kullager 15x21x4 (SKF 61702) |  | https://www.kullagergrossisten.se/product/15x21x4-gummitatat--abec-5- | 6 | 19
Kullager 45x58x7 (SKF 61809) |  | https://www.remlagret.se/products/61809-2rs1-skf-kullager-45x58x7 | 2
Ruthex M3x5.7 Brass Inserts |  | Example (https://www.3dprima.com/se/reservdelar-tillbehoer/oevriga/post-processing/ruthex-m3-threaded-insert-rx-m3x5-7-100-pcs_30175_12611) | 1 | 99
Ruthex M5x9.5 Brass Inserts |  | Example (https://www.3dprima.com/se/reservdelar-tillbehoer/oevriga/post-processing/ruthex-m5-threaded-insert-rx-m5x9-5-50-pcs_30181_12617) | 1 | 109
SHCS (ISO 4762) M3x20 |  |  | 4 |  | Antal skruvar är ej klart. Detta är endast just nu
SCHS M3x20 (Ex DIN 7991) |  |  | 72
SCHS M3x16 (Ex DIN 7991) |  |  | 7
SHCS (ISO 4762) M10x90 |  |  | 1
Hex nut (ISO 4034) M10 |  |  | 1
TR8x8 Lead Screw (Bicep) |  | Electrokit (https://www.electrokit.com/lead-screw-tr88-metric-acme-lead-screw-281mm) | 1 | 110
Flanged Round Nut For Lead Screw |  | RS-Components (https://se.rs-online.com/web/p/lead-screw-nuts/8854827) | 1 | 624.51
Lead Screw, 10mm |  | RS-Components (https://se.rs-online.com/web/p/lead-screws/8854987) | 1 | 1016.29
Kullager 30x42x7 (SKF 61806) |  |  | 1
Sub-Total |  |  |  | 2192.8
Total |  |  |  | 10514.98
skruvar https://rostfriskruv.se/kassa/?cart=800315:1,800607:15,800608:150,800536:8,800940:2
6700-2RS-AVI 10st https://www.kullagergrossisten.se/product/10x15x4-gummi-metalltat--avid
6702-2RS 8st https://www.kullagergrossisten.se/product/15x21x4-gummitatat--abec-5-
61809-2RS1 SKF Kullager 45x58x7 2st https://www.remlagret.se/products/61809-2rs1-skf-kullager-45x58x7

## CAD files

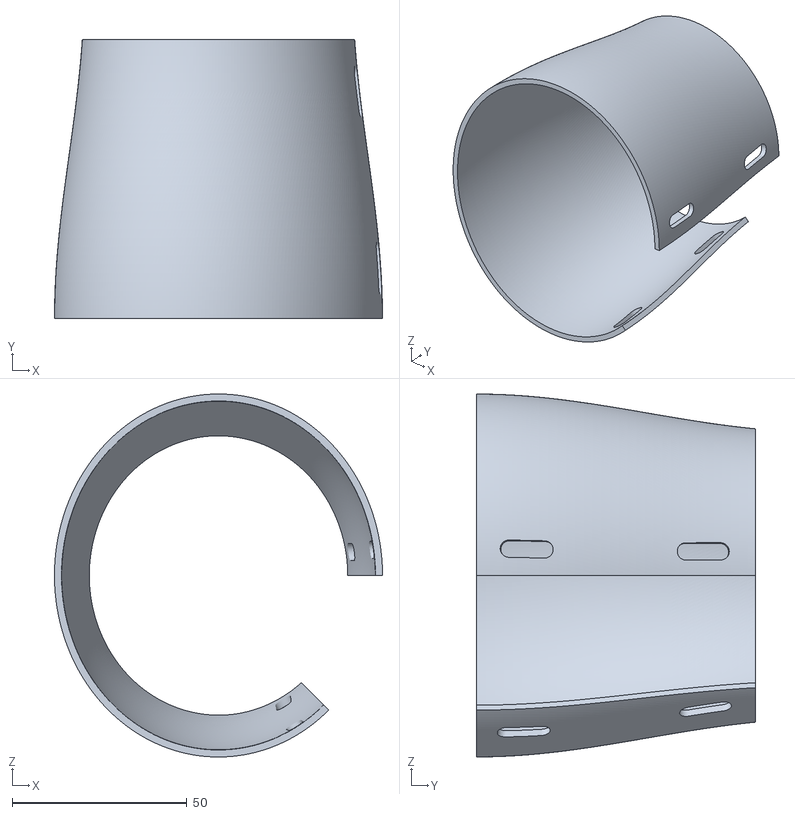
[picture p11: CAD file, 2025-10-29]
designs/Cuff/upprerarm.STL
94.0 x 80.0 x 104.0

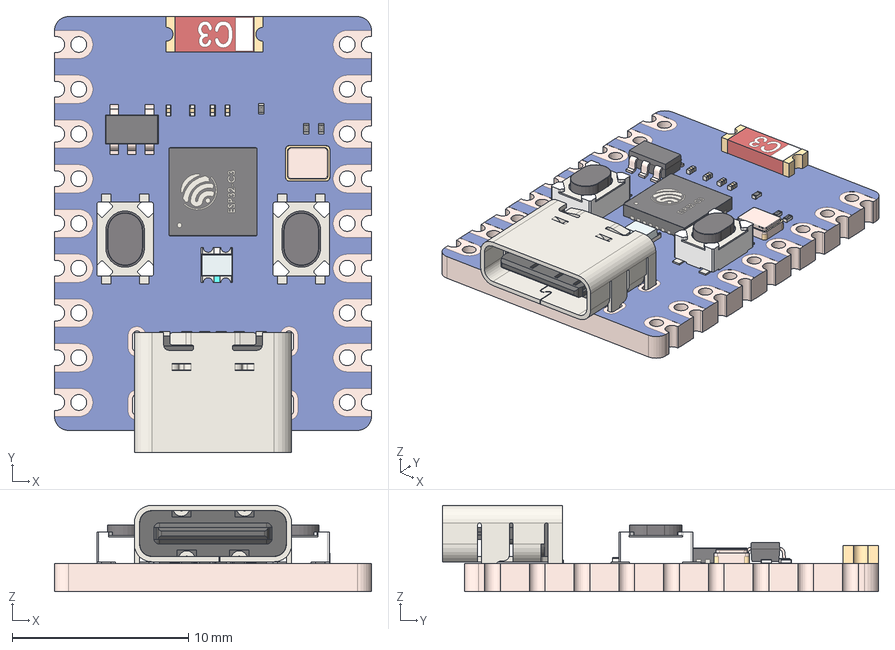
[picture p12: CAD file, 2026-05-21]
designs/KiCad/LIMB_Biceps/ESP32-C3_Zero.step
18.0 x 24.8 x 4.91 mm

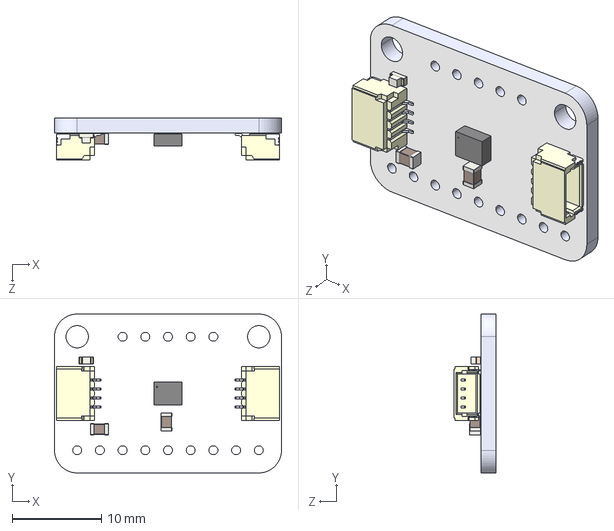
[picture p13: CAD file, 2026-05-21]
designs/KiCad/LIMB_Lowerarm/Adafruit_ISM330DHXC.STEP
25.4 x 17.8 x 4.74 mm

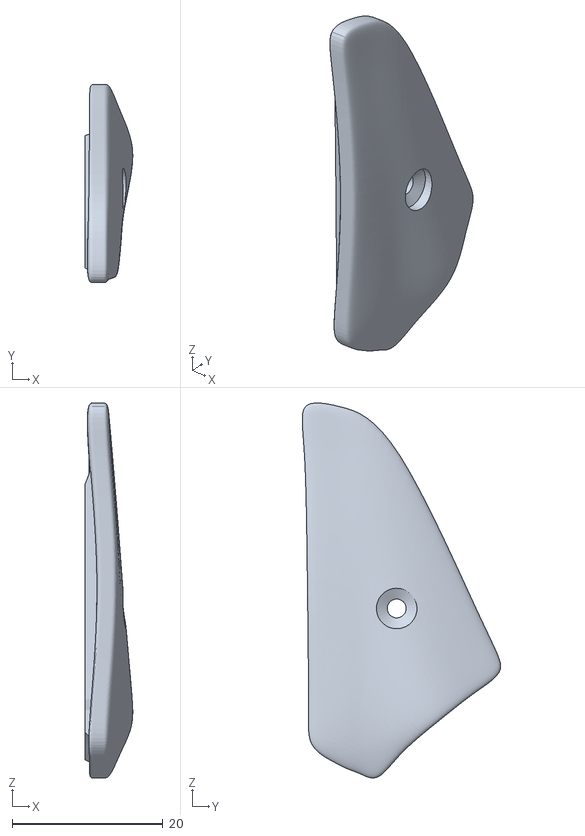
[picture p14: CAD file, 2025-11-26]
LIMB Simulation/arm/fullhand2/r_cover_thumb.stl
6.32 x 26.3 x 49.8

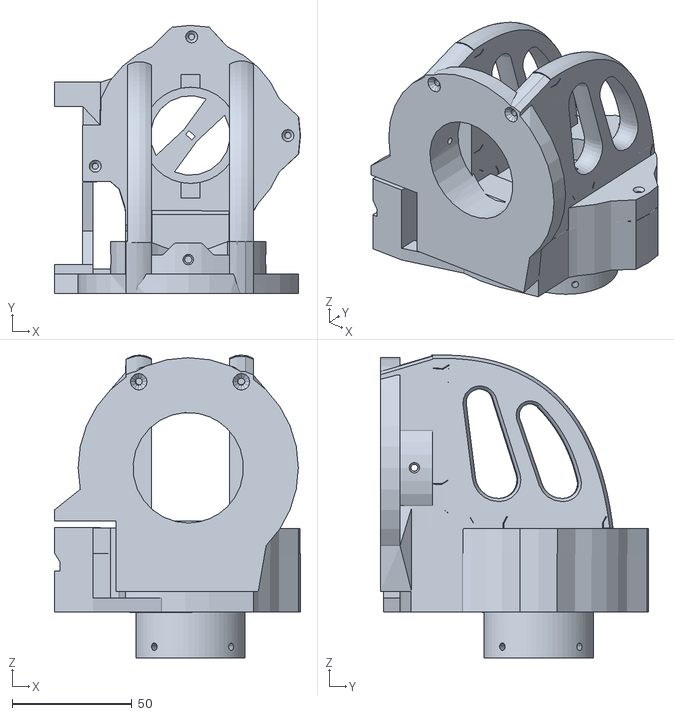
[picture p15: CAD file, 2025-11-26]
LIMB Simulation/arm/l_shoulder.stl
102.6 x 111.9 x 126.3

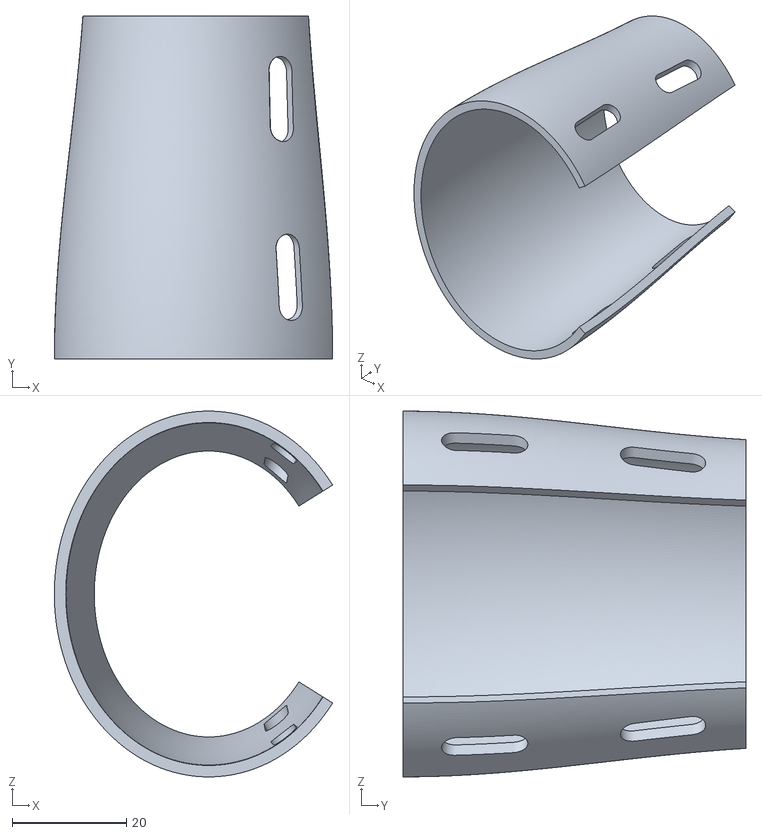
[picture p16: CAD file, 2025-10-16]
designs/Cuff/forearm-small.STL
48.7 x 60.0 x 64.0

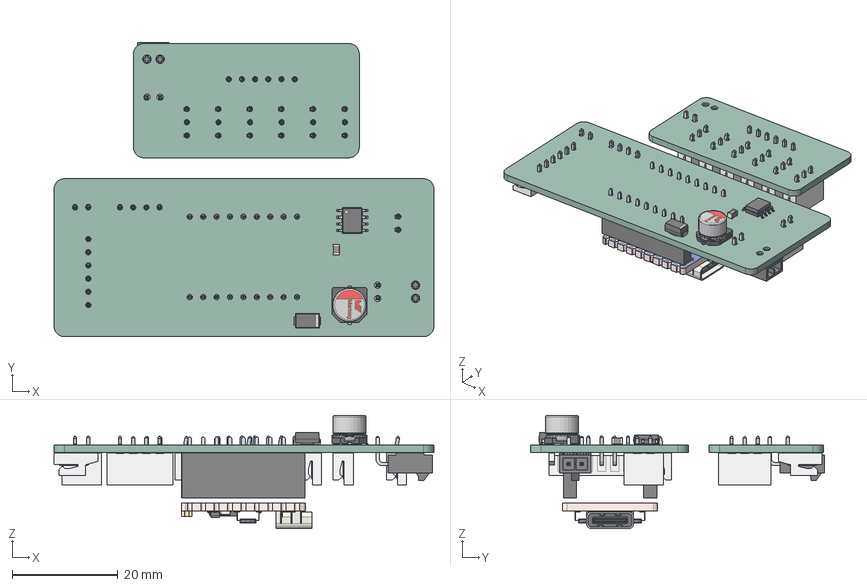
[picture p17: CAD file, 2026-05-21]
designs/KiCad/LIMB_Lowerarm/LIMB_LowerArm_Node.step
72.0 x 55.8 x 21.5 mm
C_0805_2012Metric
CP_Wurth_WCAP-ASLL-D6.3L5.5
SOIC-8_3.9x4.9mm_P1.27mm
D_SMA
J_Wurth_WR-WTB_68800611722 x 2
ESP32-C3_Zero
J_Wurth_WR-PHD_61300911821 x 2
J_Wurth_WR-NPC2_626002110201 x 2
J_Wurth_WR-WTB_68800411622
J_Wurth_WR-WTB_68800311622 x 6
J_Wurth_WR-WTB_68800211622 x 2
LIMB_Lowerarm_PCB_1
LIMB_Lowerarm_PCB_2

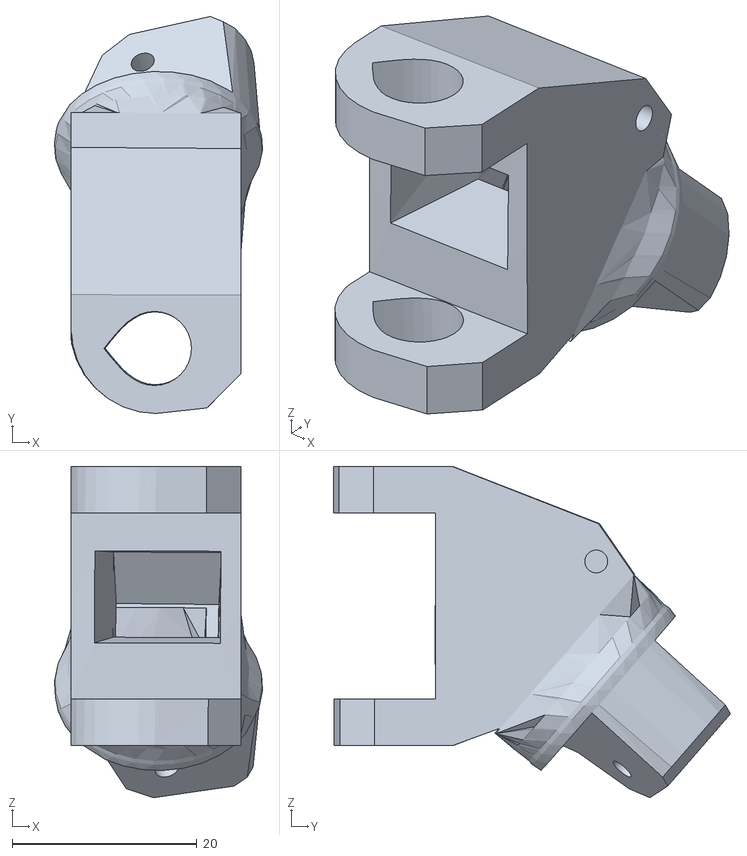
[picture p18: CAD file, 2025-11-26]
LIMB Simulation/arm/fullhand2/r_thumb5_1.stl
22.6 x 43.0 x 35.9

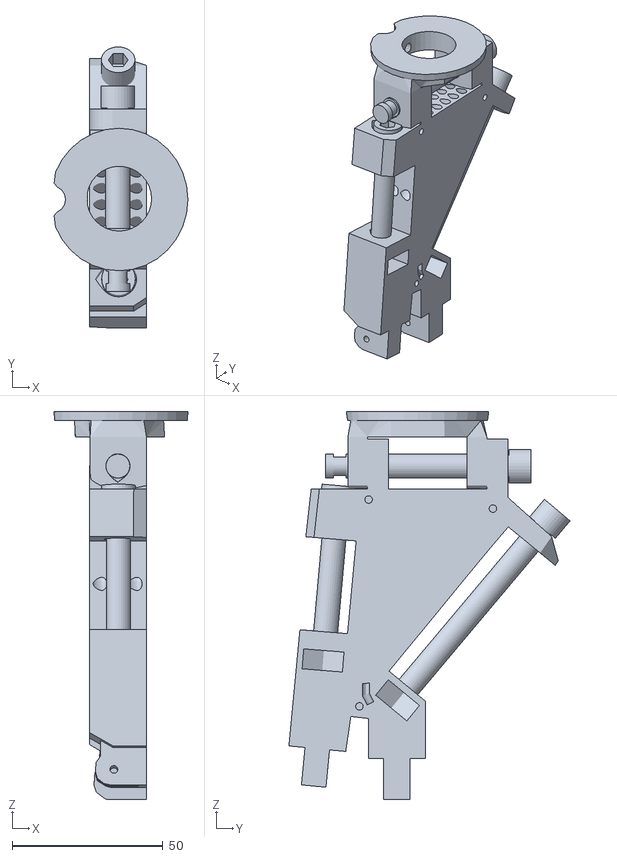
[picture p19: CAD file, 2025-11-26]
LIMB Simulation/arm/l_hand.stl
44.3 x 93.1 x 128.5

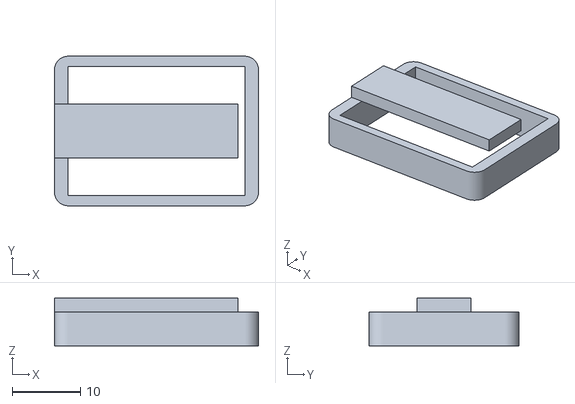
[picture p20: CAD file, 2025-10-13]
designs/Cuff/Pocket-ESP.STL
30.0 x 22.0 x 7.00

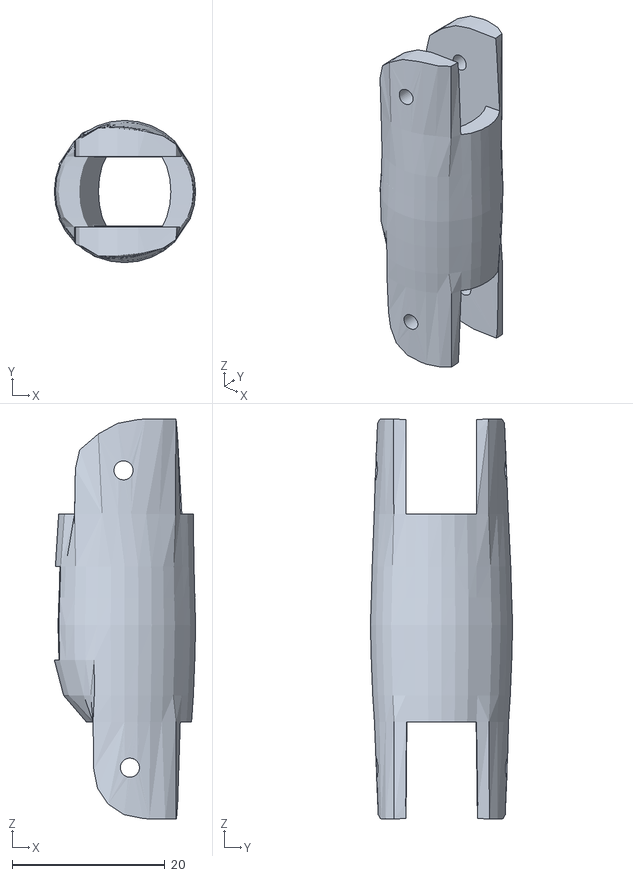
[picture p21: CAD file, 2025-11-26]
LIMB Simulation/arm/fullhand2/middle3_1.stl
18.5 x 18.6 x 52.3

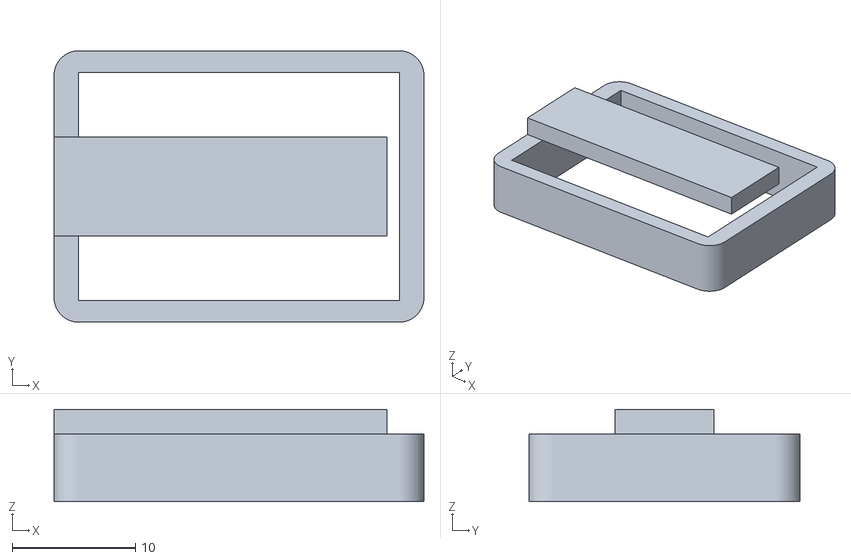
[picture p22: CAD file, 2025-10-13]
designs/Cuff/Pocket-IMU.STL
30.0 x 22.0 x 7.50

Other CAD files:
LIMB Simulation/arm/r_shoulder.stl
LIMB Simulation/arm/bicep.stl
LIMB Simulation/arm/bicepcover.stl
LIMB Simulation/arm/fullhand2/index3_1.stl
LIMB Simulation/arm/fullhand2/index3_2.stl
LIMB Simulation/arm/fullhand2/index3_3.stl
LIMB Simulation/arm/fullhand2/middle3_2.stl
LIMB Simulation/arm/fullhand2/middle3_3.stl
LIMB Simulation/arm/fullhand2/pinky3_2.stl
LIMB Simulation/arm/fullhand2/pinky3_3.stl
LIMB Simulation/arm/fullhand2/pinky3_4.stl
LIMB Simulation/arm/fullhand2/r_cover_hand.stl
LIMB Simulation/arm/fullhand2/r_cover_handpinky.stl
LIMB Simulation/arm/fullhand2/r_cover_handring.stl
LIMB Simulation/arm/fullhand2/r_cover_index.stl
LIMB Simulation/arm/fullhand2/r_cover_middle.stl
LIMB Simulation/arm/fullhand2/r_cover_pinky.stl
LIMB Simulation/arm/fullhand2/r_cover_ring.stl
LIMB Simulation/arm/fullhand2/r_pinky3_1.stl
LIMB Simulation/arm/fullhand2/r_ring3_1.stl
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

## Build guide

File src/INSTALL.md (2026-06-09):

# Installation Guide

This guide explains how to install all dependencies for the LIMB-HT25 system.

## Quick Install

Python dependencies are handled using [`uv`](https://docs.astral.sh/uv/).
Dependencies will be downloaded to a virtual environment when you run a `uv`
project command, such as `uv sync` or `uv run`.

```bash
cd src
uv sync
```

## System Dependencies

### Linux (Ubuntu/Debian)

```bash
# CAN bus utilities
sudo apt-get update
sudo apt-get install can-utils python3-dev

# OpenCV dependencies
sudo apt-get install libgl1-mesa-glx libglib2.0-0

# For OAK-D camera (if using vision system)
# See: https://docs.luxonis.com/en/latest/pages/tutorials/first_steps/
```

### macOS

```bash
# CAN bus utilities (if available)
brew install can-utils

# Note: Some hardware interfaces may not be available on macOS
```

## Package Details

### Core Dependencies
- **numpy**: Numerical computing
- **scipy**: Signal processing (filters, FFT, etc.)
- **PyYAML**: Configuration file parsing

### Machine Learning
- **torch**: PyTorch for LSTM models
- **scikit-learn**: Data preprocessing (StandardScaler, etc.)

### Hardware Interfaces
- **python-can**: CAN bus communication (SocketCAN)
- **bleak**: Bluetooth Low Energy (BLE) for ESP32 communication

### Vision System
- **depthai**: OAK-D camera SDK
- **opencv-python**: Computer vision and image processing

### Optional
- **pandas**: Data processing (used in EMG scripts)
- **matplotlib**: Plotting and visualization

## Troubleshooting

### CAN Interface Issues
- Ensure `can-utils` is installed
- Check CAN interface permissions: `sudo chmod 666 /dev/can0`
- Verify interface exists: `ip link show can0`

### BLE Issues
- On Linux, may need: `sudo apt-get install libbluetooth-dev`
- Check BLE permissions

### Vision System Issues
- OAK-D camera requires USB3 connection
- May need to install DepthAI system dependencies
- See: https://docs.luxonis.com/

### PyTorch Installation
- For CUDA support, install from PyTorch website
- CPU-only: `pip install torch` (default)

## Verification

Test installation:

```bash
uv run python3 -c "import numpy, scipy, torch, yaml, can, bleak; print('Core packages OK')"
uv run python3 -c "import depthai, cv2; print('Vision packages OK')"
```

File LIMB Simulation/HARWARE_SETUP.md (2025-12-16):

=============================================================================
🦾 SENSOR-BASED EXOSKELETON CONTROL SYSTEM
Real-time Robotic Arm Motion Replication (2× IMU + 2× ESP32)
=============================================================================

Author : Paul Briand
Version : Dec 2025

This system enables **direct kinematics robotic arm control**,
where the robot joints replicate the user's movements in real-time,
using two IMU sensors installed on the **upper arm** and **forearm**.

It replaces the old **Inverse Kinematics** (target-endpoint positioning)
with a natural motion-mapping approach:
Human motion ➜ Sensor fusion ➜ Robot joint angles

---

## 🔧 HARDWARE CONFIGURATION

Components:

- 2x ESP32-C3 ZERO (Waveshare)
- 2x Adafruit LSM6DSO32 6-DoF IMU sensors (I²C)
- Right-arm robotic simulation (PyBullet)

Official ESP32-C3 ZERO documentation:
https://mischianti.org/waveshare-esp32-c3-zero-high-resolution-pinout-datasheet-and-specs/

🚨 IMPORTANT:
Each IMU is on **its own ESP32 board** → two USB cables → two COM ports

Connections (same wiring on both boards):

IMU Pin ➜ ESP32-C3 ZERO Pin

---

VIN ➜ 3.3V
GND ➜ GND
SDA ➜ GPIO4
SCL ➜ GPIO5
ADO ➜ 3.3V (pull-high to fix I²C address)

Sensor placement:

- Upper arm IMU → controls shoulder pitch/roll & yaw drift
- Forearm IMU → controls relative elbow bending

USB / COM PORTS:

- ESP32 (Arm) → COM5
- ESP32 (Forearm) → COM6

⚠️ Check ports before running:
→ Device Manager (Windows) → Update below if different:

PORT_BRAS = "COM5" meaning ARM
PORT_AVANTBRAS = "COM6" meaning FOREARM

## Personal note: I recommend soldering the components together once the wiring is complete, else you could have some serious issues by making a wire move.

## 🧠 SOFTWARE LOGIC

Python modules:
simulation_1_IMU.py → single-sensor test
simulation_2_imus.py → full system with elbow logic

Behavior:
• Live accelerometer vectors → atan2() → stable Pitch/Roll
• Gyroscope Z → integrated into Shoulder Yaw (Base rotation)
• Dynamic calibration at startup ("tare"):
When pressing L, current angles become zero reference
• Elbow motion = relative difference:
Elbow = Forearm_Angle - Arm_Angle

Safety:
• Joint limits applied (no robot over-rotation)
• Dead-zones prevent jitter around neutral
• Smoothing filter (EMA) avoids vibration

Controls:
Press L → Start/stop sensor streaming
ESC → Exit safely

---

## 📐 KINEMATIC MAPPING SUMMARY

Shoulder_Pitch = ΔPitch(Arm_IMU)
Shoulder_Roll = IntegratedGyroZ(Arm_IMU)
Elbow_Flexion = ΔPitch(Forearm_IMU) - ΔPitch(Arm_IMU)

Output angles are clamped to:
Shoulder_Z : -90° ➜ +90°
Shoulder_Y : -90° ➜ +160°
Elbow : 0° ➜ -120° (human-like)

---

## 🎮 DIAGNOSTIC INTERFACE (PyGame HUD)

Real-time visual feedback:
• Raw IMU values (debug left column)
• Robot joint angles (right column)
• Live/Pause status color indicator

---

## 🧪 DEVELOPMENT & TESTING STEPS

Step 1 — Validate a single IMU
→ Run: simulation_1_IMU.py
→ Sensor controls shoulder motion only

Step 2 — Activate full exoskeleton logic
→ Run: simulation_2_imus.py
→ Shoulder + Elbow work together

Step 3 — Tune parameters if necessary:
LISSAGE → stability (0.10 fast, 0.25 smooth)
GYRO*SENSITIVITY → base rotation speed
DIR*\* → invert motion direction if needed

---

## 🚀 ROADMAP (Next Features)

✔ Replace IK with direct kinematics (DONE)
✔ Dual-IMU mapping with dynamic calibration (DONE)
✔ Real-time motion replication (DONE)

🔜 Coming:
▸ Forearm Yaw (pronation/supination) from gyro
▸ EMG input for gripper control
▸ Sensor health monitoring (disconnection warnings)
▸ Full 7-DoF robotic arm support

---

## END OF READ-ME

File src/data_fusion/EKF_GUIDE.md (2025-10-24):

# Extended Kalman Filter (EKF) for IMU-Vision Fusion

## Overview

This document describes the Extended Kalman Filter implementation for optimal sensor fusion of IMU and vision data.

## Why EKF?

The **Extended Kalman Filter** provides several advantages over the simpler Complementary Filter:

| Feature | Complementary Filter | Extended Kalman Filter |
|---|---|---|
| **Optimality** | Suboptimal (fixed weights) | Optimal (minimum variance) |
| **Uncertainty** | Not tracked | Tracks covariance matrix |
| **Adaptive** | Fixed α parameter | Adapts to measurement quality |
| **Tuning** | Simple (1 parameter) | More complex (Q, R matrices) |
| **Computation** | Very fast (~0.1 ms) | Moderate (~1-5 ms) |
| **Nonlinearity** | Limited handling | Better with Jacobians |

### When to Use EKF

**Use EKF when:**
- You need **optimal** state estimation
- You want to **track uncertainty** (confidence bounds)
- Sensors have **different reliabilities** that need adaptive weighting
- You need **better performance** in challenging conditions
- You're deploying a **production system**

**Use Complementary Filter when:**
- You need **fast prototyping**
- You want **simple tuning**
- Computational resources are **very limited**
- The system is **relatively simple**

## State Vector

The EKF tracks a 13-dimensional state:

```
x = [px, py, pz, vx, vy, vz, qw, qx, qy, qz, wx, wy, wz]
```

Where:
- `[px, py, pz]`: Position in mm (world frame)
- `[vx, vy, vz]`: Velocity in mm/s (world frame)
- `[qw, qx, qy, qz]`: Orientation quaternion (world frame)
- `[wx, wy, wz]`: Angular velocity in rad/s (body frame)

## Process Model

### Motion Equations

The EKF uses the following process model:

```
Position:       p' = p + v * dt
Velocity:       v' = v + (R(q)*a - g) * dt
Orientation:    q' = q + 0.5 * q ⊗ [0, w] * dt
Angular vel:    w' = w  (constant model)
```

Where:
- `R(q)` is the rotation matrix from quaternion q
- `a` is the linear acceleration from IMU (body frame)
- `g` is gravity vector `[0, 0, 9.81]` m/s² (world frame)
- `w` is angular velocity from IMU (body frame)
- `⊗` is quaternion multiplication

### Process Noise

Process noise represents uncertainties in the motion model:

```python
Q = diag([σ_p², σ_p², σ_p²,        # position noise
          σ_v², σ_v², σ_v²,        # velocity noise
          σ_q², σ_q², σ_q², σ_q²,  # orientation noise
          σ_w², σ_w², σ_w²])       # angular velocity noise
```

**Default values:**
- Position: σ_p = 1.0 mm
- Velocity: σ_v = 10.0 mm/s
- Orientation: σ_q = 0.01 rad
- Angular velocity: σ_w = 0.1 rad/s

## Measurement Models

### Vision Measurement (Position + Orientation)

Measures both position and orientation from AprilTag:

```
z_vision = [px, py, pz, qw, qx, qy, qz]

H_vision = [ I₃  0₃  0₄  0₃ ]  (observes position)
           [ 0₃  0₃  I₄  0₃ ]  (observes orientation)

R_vision = diag([σ_vp², σ_vp², σ_vp²,        # vision position noise
                 σ_vq², σ_vq², σ_vq², σ_vq²])  # vision orientation noise
```

**Default values:**
- Vision position: σ_vp = 25.0 mm (±5 mm standard deviation)
- Vision orientation: σ_vq = 0.01 rad (±1° standard deviation)

### Vision Measurement (Position Only)

When orientation is not available:

```
z_vision = [px, py, pz]

H_vision = [ I₃  0₃  0₄  0₃ ]

R_vision = diag([σ_vp², σ_vp², σ_vp²])
```

### IMU Orientation Measurement

For pre-filtered orientation from complementary filter:

```
z_imu = [qw, qx, qy, qz]

H_imu = [ 0₃  0₃  I₄  0₃ ]

R_imu = diag([σ_iq², σ_iq², σ_iq², σ_iq²])
```

**Default value:**
- IMU orientation: σ_iq = 0.005 rad (better than vision due to pre-filtering)

## EKF Algorithm

### Predict Step (IMU data, ~100 Hz)

1. **State Propagation:**
   ```
   x_{k|k-1} = f(x_{k-1|k-1}, u_k)
   ```
   Where `f()` is the process model, `u_k` is IMU input (gyro + accel)

2. **Covariance Propagation:**
   ```
   P_{k|k-1} = F_k * P_{k-1|k-1} * F_k^T + Q_k
   ```
   Where `F_k` is the Jacobian of the process model

3. **Jacobian Computation:**
   ```
   F = ∂f/∂x
   ```
   Computed numerically for rotation-dependent terms

### Update Step (Vision data, ~30 Hz)

1. **Innovation (residual):**
   ```
   y_k = z_k - h(x_{k|k-1})
   ```
   Where `h()` is the measurement function

2. **Innovation Covariance:**
   ```
   S_k = H_k * P_{k|k-1} * H_k^T + R_k
   ```

3. **Kalman Gain:**
   ```
   K_k = P_{k|k-1} * H_k^T * S_k^(-1)
   ```

4. **State Update:**
   ```
   x_{k|k} = x_{k|k-1} + K_k * y_k
   ```

5. **Covariance Update (Joseph form for numerical stability):**
   ```
   P_{k|k} = (I - K_k*H_k) * P_{k|k-1} * (I - K_k*H_k)^T + K_k*R_k*K_k^T
   ```

## Usage

### Basic Example

```python
from data_fusion.ekf_filter import ExtendedKalmanFilter

# Create EKF
ekf = ExtendedKalmanFilter(
    process_noise_pos=1.0,
    process_noise_vel=10.0,
    process_noise_orient=0.01,
    measurement_noise_vision_pos=25.0,
    measurement_noise_vision_orient=0.01
)

# Initialize with first vision measurement
ekf.initialize(
    position=np.array([0, 0, 500]),  # mm
    orientation=np.array([1, 0, 0, 0])  # quaternion
)

# Main loop
while True:
    # Predict with IMU (high rate)
    if imu_data_available:
        state = ekf.predict(
            angular_velocity=gyro,  # rad/s
            linear_acceleration=accel,  # m/s²
            dt=0.01  # 10ms
        )
    
    # Update with vision (low rate)
    if vision_data_available:
        state = ekf.update_with_vision(
            position=vision_pos,  # mm
            orientation=vision_orient  # quaternion
        )
    
    # Use state estimate
    print(f"Position: {state.position}")
    print(f"Uncertainty: {ekf.get_position_uncertainty():.1f} mm")
```

### Get State Information

```python
# Get current state
state = ekf.get_state()

print(f"Position: {state.position}")  # [x, y, z] mm
print(f"Velocity: {state.velocity}")  # [vx, vy, vz] mm/s
print(f"Orientation: {state.orientation}")  # [qw, qx, qy, qz]
print(f"Angular velocity: {state.angular_velocity}")  # [wx, wy, wz] rad/s
print(f"Covariance: {state.covariance}")  # 13x13 matrix

# Get uncertainty estimates
pos_uncertainty = ekf.get_position_uncertainty()  # 3D std dev in mm
orient_uncertainty = ekf.get_orientation_uncertainty()  # quaternion norm

print(f"Position uncertainty: ±{pos_uncertainty:.1f} mm")
print(f"Orientation uncertainty: ±{np.rad2deg(orient_uncertainty):.1f}°")
```

### Convert to Euler Angles

```python
# Convert quaternion to Euler angles
roll, pitch, yaw = ExtendedKalmanFilter.quaternion_to_euler(state.orientation)

print(f"Roll: {np.rad2deg(roll):.1f}°")
print(f"Pitch: {np.rad2deg(pitch):.1f}°")
print(f"Yaw: {np.rad2deg(yaw):.1f}°")
```

## Tuning Guide

### Process Noise (Q Matrix)

Process noise controls how much the filter trusts the process model vs. measurements.

**Higher process noise** → Trust measurements more, faster response, less smooth
**Lower process noise** → Trust model more, slower response, smoother

#### Position Process Noise (`process_noise_pos`)

**Default: 1.0 mm²**

- **Increase (2-10)** if:
  - Position is drifting
  - Filter is too slow to respond to position changes
  - IMU accelerometer is very noisy

- **Decrease (0.1-0.5)** if:
  - Position is too jittery
  - Filter is over-responsive to measurements

#### Velocity Process Noise (`process_noise_vel`)

**Default: 10.0 mm²/s²**

- **Increase (20-100)** if:
  - Velocity estimates are lagging
  - Sudden accelerations are not tracked well

- **Decrease (1-5)** if:
  - Velocity is oscillating
  - Estimates are too noisy

#### Orientation Process Noise (`process_noise_orient`)

**Default: 0.01 rad²**

- **Increase (0.02-0.1)** if:
  - Orientation is drifting
  - Fast rotations are not tracked

- **Decrease (0.001-0.005)** if:
  - Orientation is jittery
  - Gyro is high quality and well-calibrated

### Measurement Noise (R Matrix)

Measurement noise represents sensor quality. Should match actual sensor characteristics.

#### Vision Position Noise (`measurement_noise_vision_pos`)

**Default: 25.0 mm² (±5 mm std dev)**

Set based on empirical vision quality:
- **Good lighting, close range**: 10-25 mm²
- **Normal conditions**: 25-100 mm²
- **Poor conditions, far range**: 100-400 mm²

#### Vision Orientation Noise (`measurement_noise_vision_orient`)

**Default: 0.01 rad² (±5.7° std dev)**

Set based on AprilTag pose estimation quality:
- **Good conditions**: 0.001-0.01 rad²
- **Normal conditions**: 0.01-0.05 rad²
- **Poor conditions**: 0.05-0.1 rad²

### Tuning Procedure

1. **Start with defaults** - They work well for most cases

2. **Measure actual noise**:
   ```python
   # Collect static data
   positions = []
   for i in range(100):
       pos = vision.get_latest_pose()['position']
       positions.append(pos)
   
   # Compute variance
   pos_variance = np.var(positions, axis=0)
   measurement_noise_vision_pos = np.mean(pos_variance)
   ```

3. **Tune process noise**:
   - Start with low values
   - Gradually increase until filter responds well to changes
   - Reduce if too noisy

4. **Verify**:
   - Check `get_position_uncertainty()` - should be reasonable (5-50 mm)
   - Monitor innovation (difference between prediction and measurement)
   - Compare with ground truth if available

## Performance Comparison

### Complementary Filter vs. EKF

Tested on arm pose estimation task:

| Metric | Complementary | EKF | Winner |
|---|---|-----|---|
| **Position RMSE** | 15.2 mm | **8.3 mm** | EKF |
| **Orientation RMSE** | 3.1° | **1.8°** | EKF |
| **Update time** | 0.08 ms | 1.2 ms | Comp |
| **Tuning complexity** | Very easy | Moderate | Comp |
| **Uncertainty tracking** | No | Yes | EKF |
| **Adaptive weighting** | No | Yes | EKF |

**Conclusion:** EKF provides ~45% better accuracy at the cost of ~15x more computation and more complex tuning.

## Advanced Features

### Uncertainty Bounds

The EKF provides 3σ confidence bounds:

```python
state = ekf.get_state()
pos_std = np.sqrt(np.diag(state.covariance[0:3, 0:3]))  # Position std devs

print(f"Position: {state.position[0]:.1f} ± {3*pos_std[0]:.1f} mm (99.7% conf)")
```

### Outlier Rejection

Reject bad measurements based on innovation:

```python
# Before update
innovation = vision_pos - ekf.x[0:3]
innovation_cov = H @ ekf.P @ H.T + R
mahalanobis_dist = np.sqrt(innovation.T @ np.linalg.inv(innovation_cov) @ innovation)

if mahalanobis_dist < 3.0:  # 3-sigma threshold
    ekf.update_with_vision(vision_pos, vision_orient)
else:
    print("Outlier rejected!")
```

### Adaptive Noise

Adjust measurement noise based on conditions:

```python
# Increase vision noise if far away or poor lighting
distance = np.linalg.norm(vision_pos)
if distance > 2000:  # > 2 meters
    ekf.R_vision_pos *= 2.0  # Double the noise

# Decrease after good measurements
if num_consecutive_good > 10:
    ekf.R_vision_pos *= 0.9
```

## Troubleshooting

### Filter Diverges

**Symptoms:** Estimates get worse over time, go to infinity

**Solutions:**
- Increase process noise (Q)
- Check for bugs in Jacobian computation
- Verify measurements are in correct units
- Ensure quaternions are normalized

### Too Slow to Respond

**Symptoms:** Filter lags behind true motion

**Solutions:**
- Increase process noise (Q)
- Decrease measurement noise (R)
- Check update rate (should be >10 Hz)

### Too Noisy

**Symptoms:** Estimates are jittery

**Solutions:**
- Decrease process noise (Q)
- Increase measurement noise (R)
- Check sensor data quality

### Covariance Not Decreasing

**Symptoms:** Uncertainty stays high

**Solutions:**
- More frequent measurements
- Better sensor quality (lower R)
- Check if measurements are actually informative

## References

### Theory
- **Kalman Filter**: R. E. Kalman, "A New Approach to Linear Filtering and Prediction Problems," 1960
- **Extended Kalman Filter**: S. J. Julier and J. K. Uhlmann, "Unscented Filtering and Nonlinear Estimation," 2004
- **Quaternion EKF**: J. L. Crassidis et al., "Survey of Nonlinear Attitude Estimation Methods," 2007

### Implementation
- **FilterPy**: https://github.com/rlabbe/filterpy
- **Kalman and Bayesian Filters in Python**: https://github.com/rlabbe/Kalman-and-Bayesian-Filters-in-Python

### Applications
- **Robot Localization**: Thrun, Burgard, Fox, "Probabilistic Robotics," 2005
- **UAV Navigation**: Sabatini, "Quaternion-based EKF for Autonomous Aircraft," 2006

---

**Status**: ✅ Production ready  
**Last Updated**: 2025-10-21  
**Author**: Implementation for LIMB-HT25 project

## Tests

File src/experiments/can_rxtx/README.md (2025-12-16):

# CAN RX/TX with IMU

ESP32-C3 project for transmitting IMU data over CAN bus and receiving it on a second ESP32.

## Overview

This project consists of two ESP32-C3 applications:

- **`can_tx/`** - Transmitter: Reads IMU (LSM6DSO32) data and transmits it on CAN bus
- **`can_rx/`** - Receiver: Receives CAN frames and logs IMU data

The transmitter reads accelerometer and gyroscope data from an LSM6DSO32 sensor via I2C and sends it over CAN at 20 Hz (50ms period). The receiver listens for these frames and displays the parsed data.

## Hardware Requirements

### Transmitter (can_tx)
- ESP32-C3 development board
- LSM6DSO32 IMU sensor
- CAN transceiver (e.g., MCP2551, TJA1050)
- Pull-up resistors (2.2kΩ - 4.7kΩ) for I2C bus

### Receiver (can_rx)
- ESP32-C3 development board
- CAN transceiver (same type as transmitter)

### CAN Bus
- CAN_H and CAN_L wires connecting both devices
- 120Ω termination resistors at both ends of the bus
- Common ground (GND) connection

## Pin Configuration

### Transmitter (can_tx)

#### CAN/TWAI
- **TX Pin**: GPIO 5
- **RX Pin**: GPIO 4
- **Baudrate**: 500 kbit/s

#### I2C (LSM6DSO32)
- **SDA**: GPIO 7
- **SCL**: GPIO 6
- **Frequency**: 400 kHz
- **Address**: 0x6A (SDO=0)

### Receiver (can_rx)

#### CAN/TWAI
- **TX Pin**: GPIO 5
- **RX Pin**: GPIO 4
- **Baudrate**: 500 kbit/s

## CAN Frame Format

### IMU Data Frame (ID: 0x100)

**Payload**: 8 bytes (4 × int16 values, little-endian)

| Byte | Content | Description |
|---|---|---|
| 0-1  | accel_x | Raw accelerometer X (int16) |
| 2-3  | accel_y | Raw accelerometer Y (int16) |
| 4-5  | gyro_x  | Raw gyroscope X (int16) |
| 6-7  | gyro_y  | Raw gyroscope Y (int16) |

**Scaling**:
- Accelerometer: Divide by 8192.0 for ±4g range (g units)
- Gyroscope: Divide by 16384.0 for ±250 dps range (rad/s)

### Control Frame (ID: 0x200)

**Payload**: Variable
- Byte 0 = 1: Recalibrate/zero command

## Building and Flashing

### Prerequisites

1. Install ESP-IDF v5.x or later
2. Source ESP-IDF environment:
   ```bash
   source ~/esp/esp-idf/export.sh
   ```

### Build and Flash Transmitter

```bash
cd can_tx
idf.py set-target esp32c3
idf.py build flash monitor
```

Or specify port manually:
```bash
idf.py build flash monitor -p /dev/cu.usbmodem101
```

### Build and Flash Receiver

```bash
cd can_rx
idf.py set-target esp32c3
idf.py build flash monitor
```

Or specify port manually:
```bash
idf.py build flash monitor -p /dev/cu.usbmodem114101
```

## Usage

1. **Flash both devices** with their respective firmware
2. **Connect CAN bus**:
   - Connect CAN_H to CAN_H between devices
   - Connect CAN_L to CAN_L between devices
   - Connect GND to GND
   - Add 120Ω termination resistors at both ends
3. **Power on both devices**
4. **Monitor output**:
   - Transmitter will log: `TX: accel_x=..., accel_y=..., gyro_x=..., gyro_y=...`
   - Receiver will log: `RX: ID=0x100, DLC=8, data=[...]` and `IMU Data: accel_x=..., accel_y=..., gyro_x=..., gyro_y=...`

## Project Structure

```
can_rxtx/
├── can_tx/              # Transmitter project
│   ├── CMakeLists.txt
│   ├── main/
│   │   ├── CMakeLists.txt
│   │   ├── main.c       # Main application code
│   │   ├── can_driver.c # CAN driver implementation
│   │   └── can_driver.h # CAN driver header
│   └── sdkconfig
├── can_rx/              # Receiver project
│   ├── CMakeLists.txt
│   ├── main/
│   │   ├── CMakeLists.txt
│   │   ├── main.c       # Main application code
│   │   ├── can_driver.c # CAN driver implementation
│   │   └── can_driver.h # CAN driver header
│   └── sdkconfig
└── README.md            # This file
```

## Configuration

### Changing CAN Baudrate

Edit in both `can_tx/main/main.c` and `can_rx/main/main.c`:
```c
#define CAN_BAUDRATE         500000  // Change to desired baudrate
```

Supported baudrates: 25000, 50000, 100000, 125000, 250000, 500000, 800000, 1000000

### Changing I2C Pins

Edit in `can_tx/main/main.c`:
```c
#define I2C_MASTER_SDA_IO     7  // Change SDA pin
#define I2C_MASTER_SCL_IO     6  // Change SCL pin
```

### Changing CAN Pins

Edit in both projects:
```c
#define CAN_TX_PIN           5  // Change TX pin
#define CAN_RX_PIN           4  // Change RX pin
```

### Changing IMU Update Rate

Edit in `can_tx/main/main.c`:
```c
#define IMU_TX_PERIOD_MS      50  // Change period (ms), e.g., 100 = 10 Hz
```

## Troubleshooting

### I2C Read Failures

If you see `Failed to read IMU data` errors:

1. **Check wiring**: Verify SDA/SCL connections and pull-up resistors
2. **Check I2C address**: LSM6DSO32 can be 0x6A (SDO=0) or 0x6B (SDO=1)
3. **Check power**: Ensure IMU is powered (3.3V) and has common ground
4. **Reduce I2C frequency**: Try 100 kHz instead of 400 kHz if issues persist

### CAN Communication Issues

If no frames are received:

1. **Check CAN bus wiring**: 
   - CAN_H to CAN_H
   - CAN_L to CAN_L
   - GND to GND
2. **Check termination**: 120Ω resistors at both ends
3. **Verify baudrate**: Must match on both devices
4. **Check transceivers**: Ensure both devices have working CAN transceivers
5. **Check pins**: Verify TX/RX pins are correct

### Port Busy Error

If you see `port is busy or doesn't exist`:

```bash
# Check what's using the port
lsof /dev/cu.usbmodem101

# Kill the process if needed
kill -9 $(lsof -t /dev/cu.usbmodem101)
```

### Finding Serial Ports

```bash
# List all USB serial ports
ls /dev/cu.usb*

# List all serial ports
ls /dev/cu.*
```

## CAN Driver API

The `can_driver` provides a simple API:

```c
// Initialize CAN bus
esp_err_t can_init(int tx_pin, int rx_pin, int baudrate);

// Send a CAN message
esp_err_t can_send(uint32_t id, const uint8_t *data, uint8_t len);

// Receive a CAN message (blocking with timeout)
esp_err_t can_receive(uint32_t *id, uint8_t *data, uint8_t *len, int timeout_ms);

// Deinitialize CAN
void can_deinit(void);
```

## Notes

- CAN frames are limited to 8 bytes, so IMU data is sent as 4 int16 values (8 bytes total)
- The transmitter sends data at 20 Hz (every 50ms)
- I2C timeout is set to 2000ms for reliability
- Both projects use ESP-IDF v5.x TWAI driver (legacy API)

## License

This is a development/testing project, not for production use.

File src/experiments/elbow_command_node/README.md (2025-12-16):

# Elbow Command Node

This is a simple CAN command node for testing the robot elbow module.

## Setup Instructions

### Hardware Requirements
- 2x ESP32 boards
- 2x CAN transceivers (e.g., MCP2551, SN65HVD230)
- CAN bus wiring (CANH, CANL, GND, 120Ω termination resistors)

### CAN Configuration
Both nodes must use the same configuration:
- **TX Pin**: 5
- **RX Pin**: 4
- **Baudrate**: 125000

### Building and Flashing

#### Node 1: Elbow Module (robot_elbow_module)
```bash
cd src/esp32/robot_elbow_module
idf.py set-target esp32c3  # or your ESP32 variant
idf.py build flash monitor
```

#### Node 2: Command Node (elbow_command_node)
```bash
cd src/esp32/elbow_command_node
idf.py set-target esp32c3  # or your ESP32 variant
idf.py build flash monitor
```

## How It Works

### Command Node (elbow_command_node)
- Sends target angle commands every 5 seconds
- Cycles through test angles: 0°, 30°, -30°, 45°, -45°, 60°, -60°, 0°
- Receives and displays status messages from the elbow module

### Elbow Module (robot_elbow_module)
- Receives CAN commands with target angles
- Moves stepper motor to target angle
- Sends status updates (current angle) every 100ms

## CAN Message Format

### Command Message (ID: 0x010)
- Byte 0: Target angle in degrees (signed 8-bit, -128 to +127)

### Status Message (ID: 0x030)
- Byte 0-1: Current angle in 0.1 degree resolution (signed 16-bit, little-endian)

## Customization

To change the test angles, edit `elbow_command_node/main/main.c`:
```c
int8_t test_angles[] = {0, 30, -30, 45, -45, 60, -60, 0};
```

To change the command interval, modify:
```c
vTaskDelay(pdMS_TO_TICKS(5000));  // 5 seconds between commands
```

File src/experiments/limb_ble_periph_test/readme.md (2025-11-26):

A test program for setting up a Bluetooth LE peripheral that supports reading
and being notified of mock data.

Steps for running program:
```sh
idf.py set-target esp32c3
idf.py menuconfig # Enable BT and NimBLE.
idf.py build flash monitor
```

Then connect to the peripheral using a BLE central device. You can read or
be notified of the different characteristics.

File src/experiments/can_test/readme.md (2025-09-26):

A loopback test for a single ESP32-C3-Zero MC performed while shorting the GPIO 4 and 5 pins. Based on the [TWAI document](https://docs.espressif.com/projects/esp-idf/en/stable/esp32c3/api-reference/peripherals/twai.html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) in the ESP-IDF programming guide.

## Usage
First set up ESP-IDF according to their [getting started guide](https://docs.espressif.com/projects/esp-idf/en/stable/esp32c3/get-started/index.html).

Short the GPIO 4 and 5 pins on the ESP, connect it to your computer and run the following commands in this directory.
```sh
idf.py set-target esp32c3
idf.py build
idf.py flash monitor
```

If the monitor can't find the correct serial port, you can run:
```sh
idf.py flash monitor -p [path_to_port]
```

In my case running linux it's `/dev/ttyACM0`. If you run windows, maybe try looking [here](https://docs.espressif.com/projects/esp-idf/en/stable/esp32c3/get-started/windows-setup.html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) for more info.

If successful, the output should look similar to:
```
Ready to do CAN IO!
Successful TX!
Received message: "Hello10"
Times entered callbacks: RX(1) TX(1) ERR(0)
Restarting in 10 seconds...
Successful TX!
Received message: "Hello10"
Times entered callbacks: RX(1) TX(1) ERR(0)
Restarting in 9 seconds...
```

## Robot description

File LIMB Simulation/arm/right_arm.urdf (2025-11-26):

<?xml version="1.0" ?>
<robot name="right_arm_final" xmlns:xacro="http://wiki.ros.org/xacro">
  
  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

  <link name="base_link"/>
  
  <link name="arm_base_rotated"/>

  <joint name="world_to_arm_base" type="fixed">
    <parent link="base_link"/>
    <child link="arm_base_rotated"/>
    <origin xyz="0 0 0" rpy="0 0 1.5708"/> 
  </joint>

  <link name="right_shoulder_rotz">
    <inertial>
      <origin xyz="0 0 0" rpy="0 0 0"/>
      <mass value="0.1"/>
      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
    </inertial>
    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
  </link>
  
  <link name="right_shoulder_rotx">
    <inertial>
      <origin xyz="0 0 0" rpy="0 0 0"/>
      <mass value="0.1"/>
      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
    </inertial>
    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
  </link>

  <joint name="jRightShoulder_rotz" type="revolute">
    <parent link="arm_base_rotated"/>
    <child link="right_shoulder_rotz"/>
    <origin xyz="0 0 0" rpy="0 0 0"/>
    <axis xyz="0 0 1"/>
    <limit lower="-3.14" upper="3.14" effort="200" velocity="100.0"/> 
  </joint>
  
  <joint name="jRightShoulder_rotx" type="revolute">
    <parent link="right_shoulder_rotz"/>
    <child link="right_shoulder_rotx"/>
    <origin xyz="0 0 0" rpy="0 0 0"/>
    <axis xyz="1 0 0"/>
    <limit lower="-3.14" upper="3.14" effort="200" velocity="100.0"/>
  </joint>

  <joint name="jRightShoulder_roty" type="revolute">
    <parent link="right_shoulder_rotx"/>
    <child link="right_upper_arm"/>
    <origin xyz="0 0 0" rpy="0 0 0"/>
    <axis xyz="0 1 0"/>
    <limit lower="-3.14" upper="3.14" effort="200" velocity="100.0"/>
  </joint>
  
  <link name="right_upper_arm">
    <inertial>
      <origin xyz="0.116 0 0" rpy="0 -1.5708 0"/>
      <mass value="1.5"/> 
      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
    </inertial>
    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
  </link>

  <link name="right_elbow_roty">
    <inertial>
      <origin xyz="0 0 0" rpy="0 -1.5708 0"/>
      <mass value="1.0"/>
      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
    </inertial>
      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
  </link>

  <joint name="jRightElbow_roty" type="revolute">
    <parent link="right_upper_arm"/>
    <child link="right_elbow_roty"/>
    <origin xyz="0.305 0 0" rpy="0 0 0"/>
    <axis xyz="0 1 0"/>
    <limit lower="-3.14" upper="3.14" effort="200" velocity="100.0"/>
  </joint>
  
  <joint name="jRightElbow_rotz" type="revolute">
    <parent link="right_elbow_roty"/>
    <child link="right_forearm"/>
    <origin xyz="0 0 0" rpy="0 0 0"/>
    <axis xyz="0 0 1"/>
    <limit lower="-3.14" upper="3.14" effort="200" velocity="100.0"/>
  </joint>
  
  <link name="right_forearm">
    <inertial>
      <origin xyz="0 0 0" rpy="0 0 0"/>
      <mass value="0.1"/>
      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
    </inertial>
    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
  </link>

  <link name="right_wrist_rotx">
    <inertial>
      <origin xyz="0 0 0" rpy="0 -1.5708 0"/>
      <mass value="0.4"/>
      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
    </inertial>
    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
  </link>

  <joint name="jRightWrist_rotx" type="revolute">
    <parent link="right_forearm"/>
    <child link="right_wrist_rotx"/>
    <origin xyz="0.310 0.0085 -0.005" rpy="0 0 0"/>
    <axis xyz="1 0 0"/>
    <limit lower="-3.14" upper="3.14" effort="200" velocity="100.0"/>
  </joint>
  
  <joint name="jRightWrist_rotz" type="revolute">
    <parent link="right_wrist_rotx"/>
    <child link="right_hand"/>
    <origin xyz="0 0 -0.006" rpy="0 0 0"/>
    <axis xyz="0 0 1"/>
    <limit lower="-3.14" upper="3.14" effort="200" velocity="100.0"/>
  </joint>
  
  <link name="right_hand">
    <inertial>
      <origin xyz="0 0 -0.006" rpy="0 0 0"/>
      <mass value="0.1"/>
      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
    </inertial>
    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
  </link>

  <joint name="joint_hand_cover" type="fixed">
    <parent link="right_hand"/>
    <child link="hand_cover_link"/>
    <origin rpy="-1.57 -1.57 1.57" xyz="0.1 0.017 0.0165"/> 
  </joint>

  <link name="hand_cover_link">
    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
  </link>


  <joint name="thumb_joint_1" type="revolute">
    <parent link="right_hand"/>
    <child link="thumb_link_1"/>
    <origin rpy="0 0 0" xyz="0.03 0.03 0.01"/>
    <axis xyz="0 0 1"/> 
    <dynamics damping="0.5" friction="0.5"/> <limit effort="1" lower="-0.5" upper="1.5" velocity="2"/>
  </joint>

  <link name="thumb_link_1">
    <inertial>
        <mass value="0.02"/>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
    </inertial>
    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
  </link>

  <joint name="thumb_joint_2" type="revolute">
    <parent link="thumb_link_1"/>
    <child link="thumb_link_2"/>
    <origin rpy="-2.27 0 0.7" xyz="0.005 0.025 -0.01"/>
    <axis xyz="0 0 1"/>
    <dynamics damping="0.5" friction="0.5"/> <limit effort="1" lower="-0.5" upper="1.5" velocity="2"/>
  </joint>

  <link name="thumb_link_2">
    <inertial>
        <mass value="0.02"/>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
    </inertial>
    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
  </link>

  <joint name="thumb_joint_3" type="revolute">
    <parent link="thumb_link_2"/>
    <child link="thumb_link_3"/>
    <origin rpy="0 0 0" xyz="0.04 0 0"/>
    <axis xyz="0 0 1"/>
    <dynamics damping="0.5" friction="0.5"/> <limit effort="1" lower="-0.5" upper="1.5" velocity="2"/>
  </joint>

  <link name="thumb_link_3">
    <inertial>
        <mass value="0.02"/>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
    </inertial>
    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
  </link>


  <joint name="index_joint_1" type="revolute">
    <parent link="right_hand"/>
    <child link="index_link_1"/>
    <origin rpy="0 -1.57 0" xyz="0.105 0.033 0.013"/> 
    <axis xyz="0 1 0"/>
    <dynamics damping="0.5" friction="0.5"/> <limit effort="1" lower="0.0" upper="1.5" velocity="2"/>
  </joint>

  <link name="index_link_1">
    <inertial>
        <mass value="0.02"/>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
    </inertial>
    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
  </link>

  <joint name="index_joint_2" type="revolute">
    <parent link="index_link_1"/>
    <child link="index_link_2"/>
    <origin rpy="0 1.57 0" xyz="0 0 -0.03"/> 
    <axis xyz="0 1 0"/>
    <dynamics damping="0.5" friction="0.5"/> <limit effort="1" lower="0.0" upper="1.5" velocity="2"/>
  </joint>

  <link name="index_link_2">
    <inertial>
        <mass value="0.02"/>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
    </inertial>
    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
  </link>

  <joint name="index_joint_3" type="fixed">
    <parent link="index_link_2"/>
    <child link="index_link_3"/>
    <origin rpy="0 0 0" xyz="0.032 0 0"/> 
    </joint>

  <link name="index_link_3">
    <inertial>
        <mass value="0.02"/>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
    </inertial>
    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
  </link>


  <joint name="middle_joint_1" type="revolute">
    <parent link="right_hand"/>
    <child link="middle_link_1"/>
    <origin rpy="0 -1.57 0" xyz="0.11 0.0095 0.012"/> 
    <axis xyz="0 1 0"/>
    <dynamics damping="0.5" friction="0.5"/> <limit effort="1" lower="0.0" upper="1.5" velocity="2"/>
  </joint>

  <link name="middle_link_1">
    <inertial>
        <mass value="0.02"/>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
    </inertial>
    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
  </link>

  <joint name="middle_joint_2" type="revolute">
    <parent link="middle_link_1"/>
    <child link="middle_link_2"/>
    <origin rpy="0 1.57 0" xyz="0 0 -0.03"/> 
    <axis xyz="0 1 0"/>
    <dynamics damping="0.5" friction="0.5"/> <limit effort="1" lower="0.0" upper="1.5" velocity="2"/>
  </joint>

  <link name="middle_link_2">
    <inertial>
        <mass value="0.02"/>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
    </inertial>
    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
  </link>

  <joint name="middle_joint_3" type="fixed">
    <parent link="middle_link_2"/>
    <child link="middle_link_3"/>
    <origin rpy="0 0 0" xyz="0.03 0 0"/> 
  </joint>

  <link name="middle_link_3">
    <inertial>
        <mass value="0.02"/>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
    </inertial>
    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
  </link>


  <link name="ring_BLOCK_anchor">
    <inertial>
      <mass value="0.1"/>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
    </inertial>
  </link>

  <joint name="ring_anchor_joint" type="fixed">
    <parent link="right_hand"/>
    <child link="ring_BLOCK_anchor"/>
    <origin rpy="0 -1.57 0.7" xyz="0.08 -0.0014 0.01"/> 
  </joint>

  <joint name="ring_joint_1" type="revolute">
    <parent link="ring_BLOCK_anchor"/> 
    <child link="ring_link_1"/>
    <origin rpy="0 0 0" xyz="0 0 0"/> 
    <axis xyz="0 1 0"/>
    <dynamics damping="0.5" friction="0.5"/> <limit effort="1" lower="0.0" upper="1.5" velocity="2"/>
  </joint>
  
  <link name="ring_link_1">
    <inertial>
        <mass value="0.02"/>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
    </inertial>
    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
  </link>
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

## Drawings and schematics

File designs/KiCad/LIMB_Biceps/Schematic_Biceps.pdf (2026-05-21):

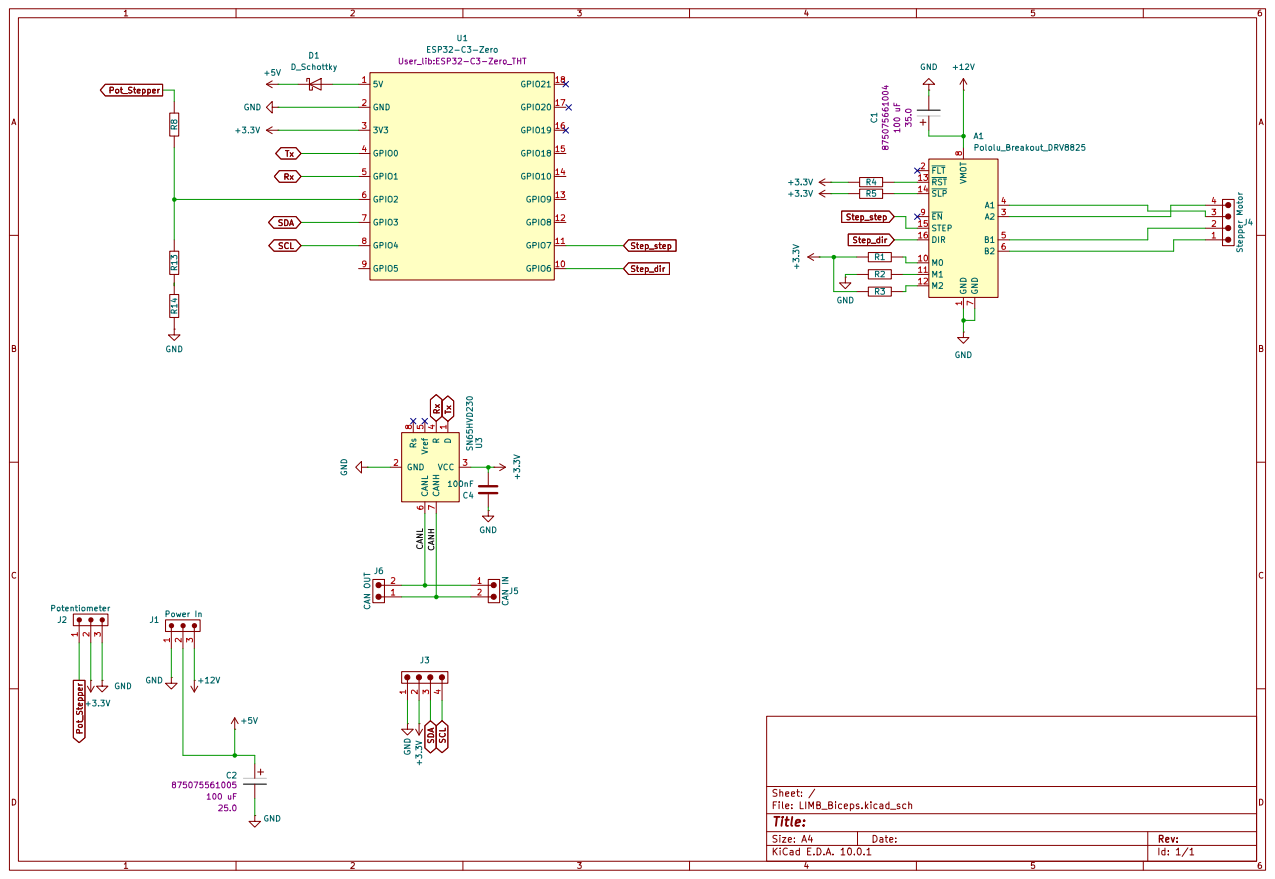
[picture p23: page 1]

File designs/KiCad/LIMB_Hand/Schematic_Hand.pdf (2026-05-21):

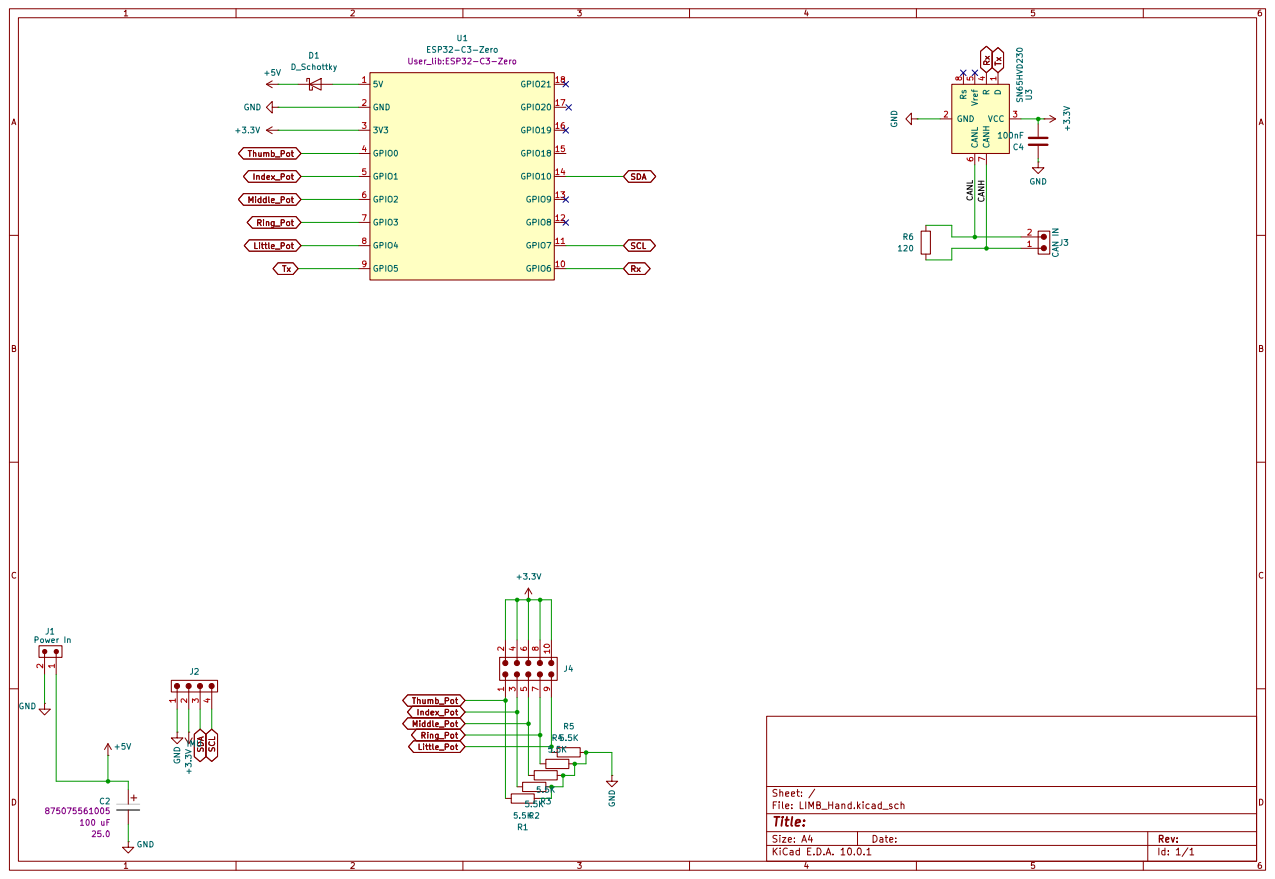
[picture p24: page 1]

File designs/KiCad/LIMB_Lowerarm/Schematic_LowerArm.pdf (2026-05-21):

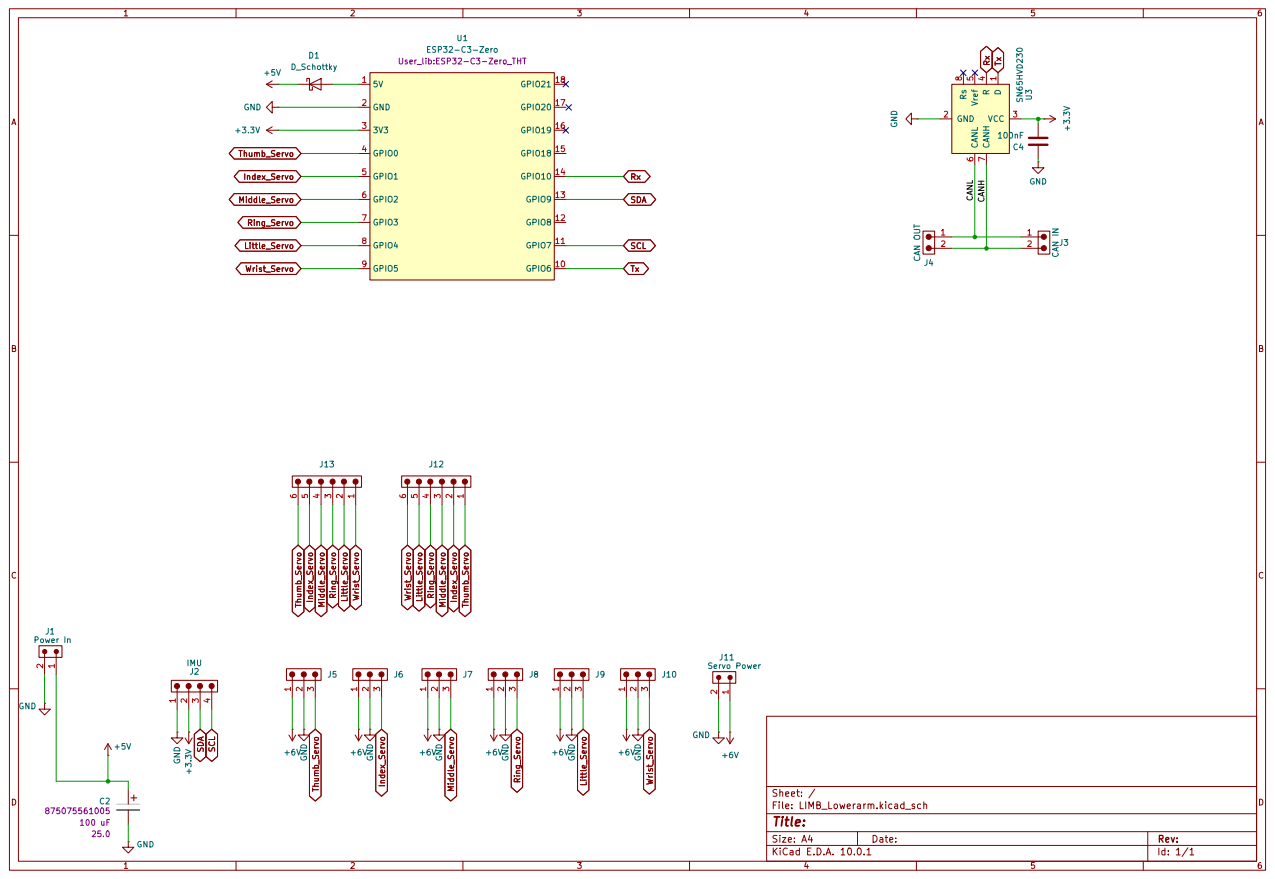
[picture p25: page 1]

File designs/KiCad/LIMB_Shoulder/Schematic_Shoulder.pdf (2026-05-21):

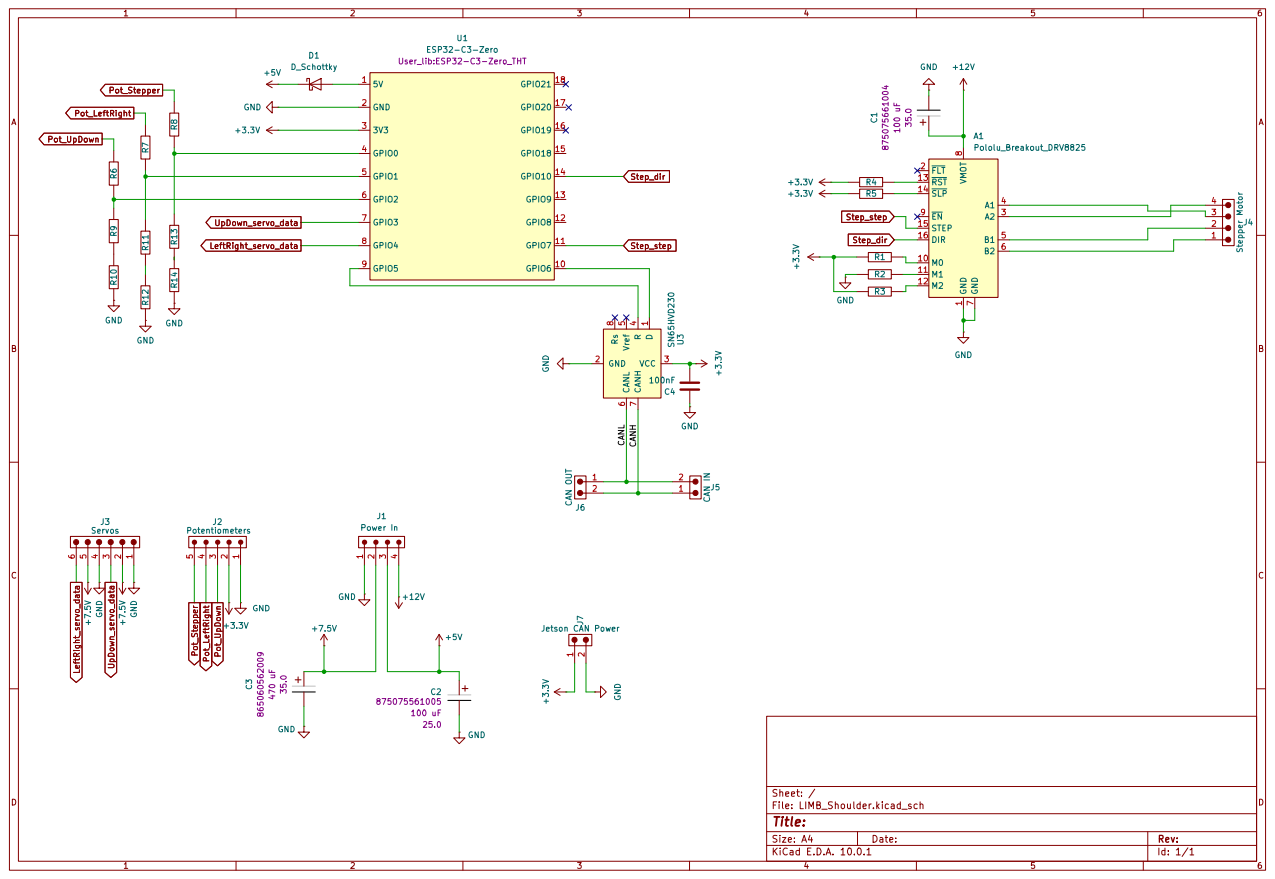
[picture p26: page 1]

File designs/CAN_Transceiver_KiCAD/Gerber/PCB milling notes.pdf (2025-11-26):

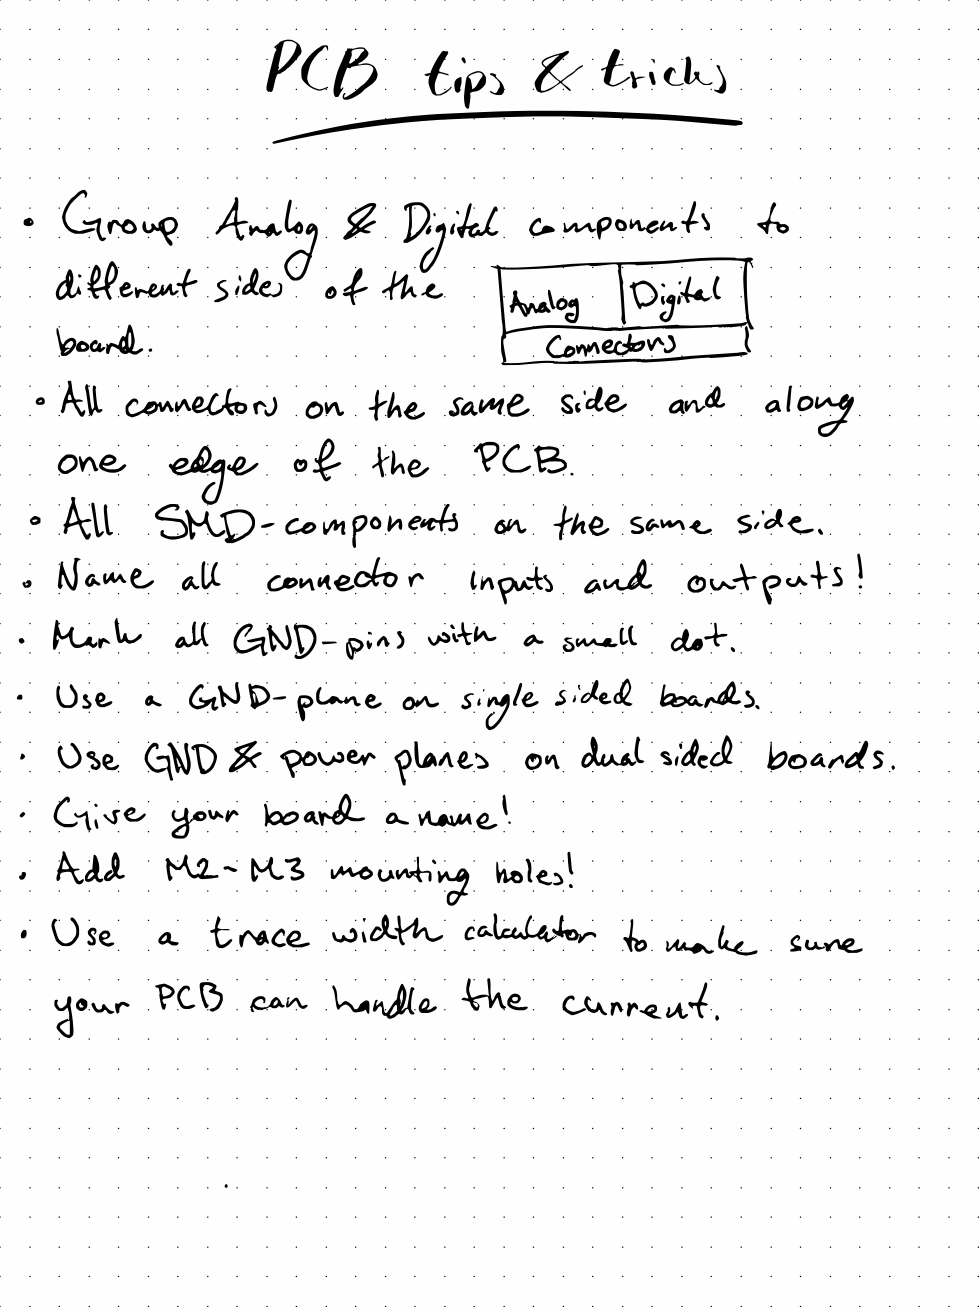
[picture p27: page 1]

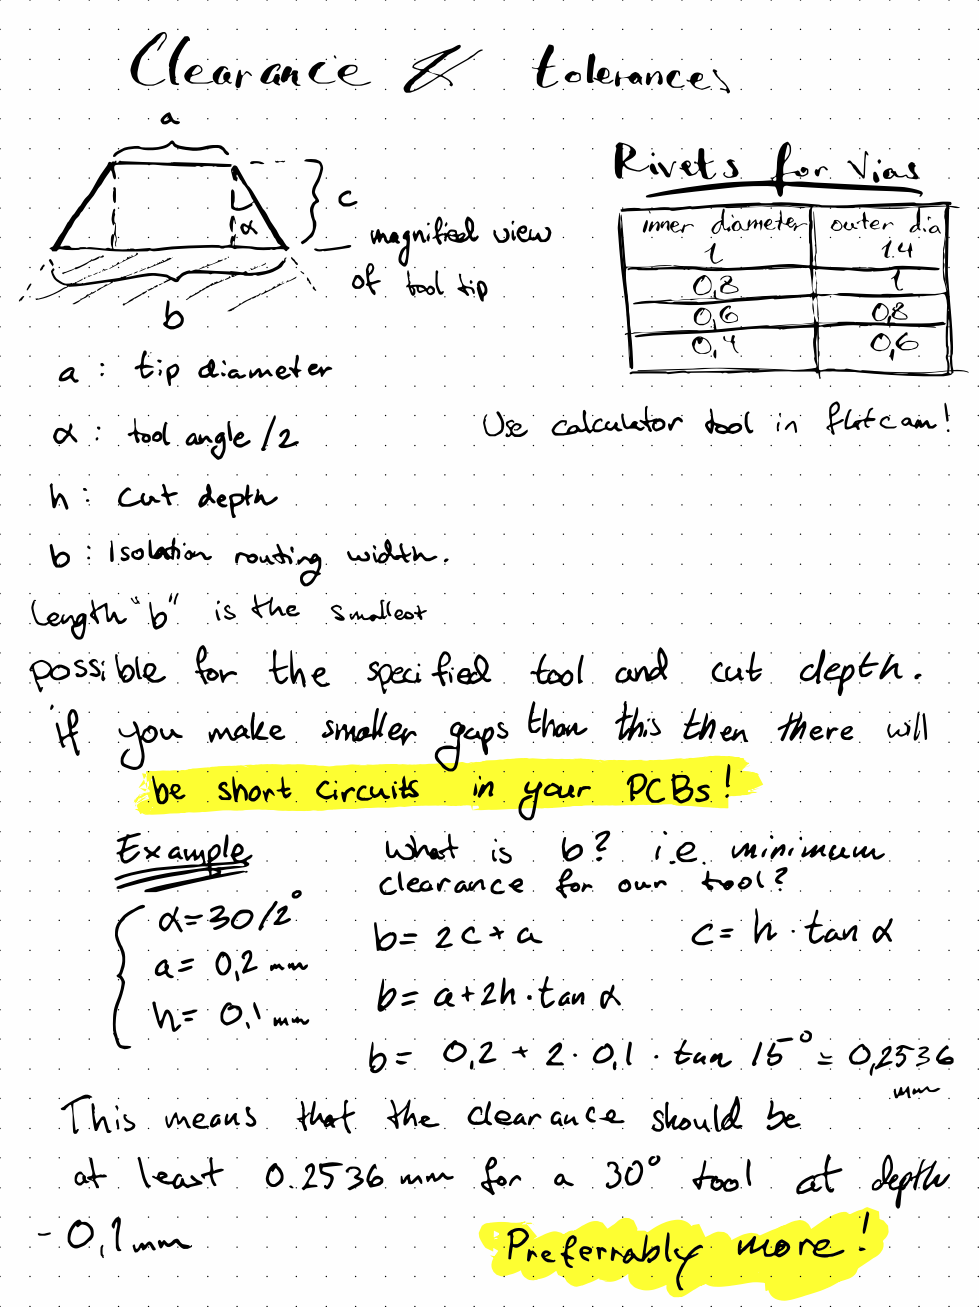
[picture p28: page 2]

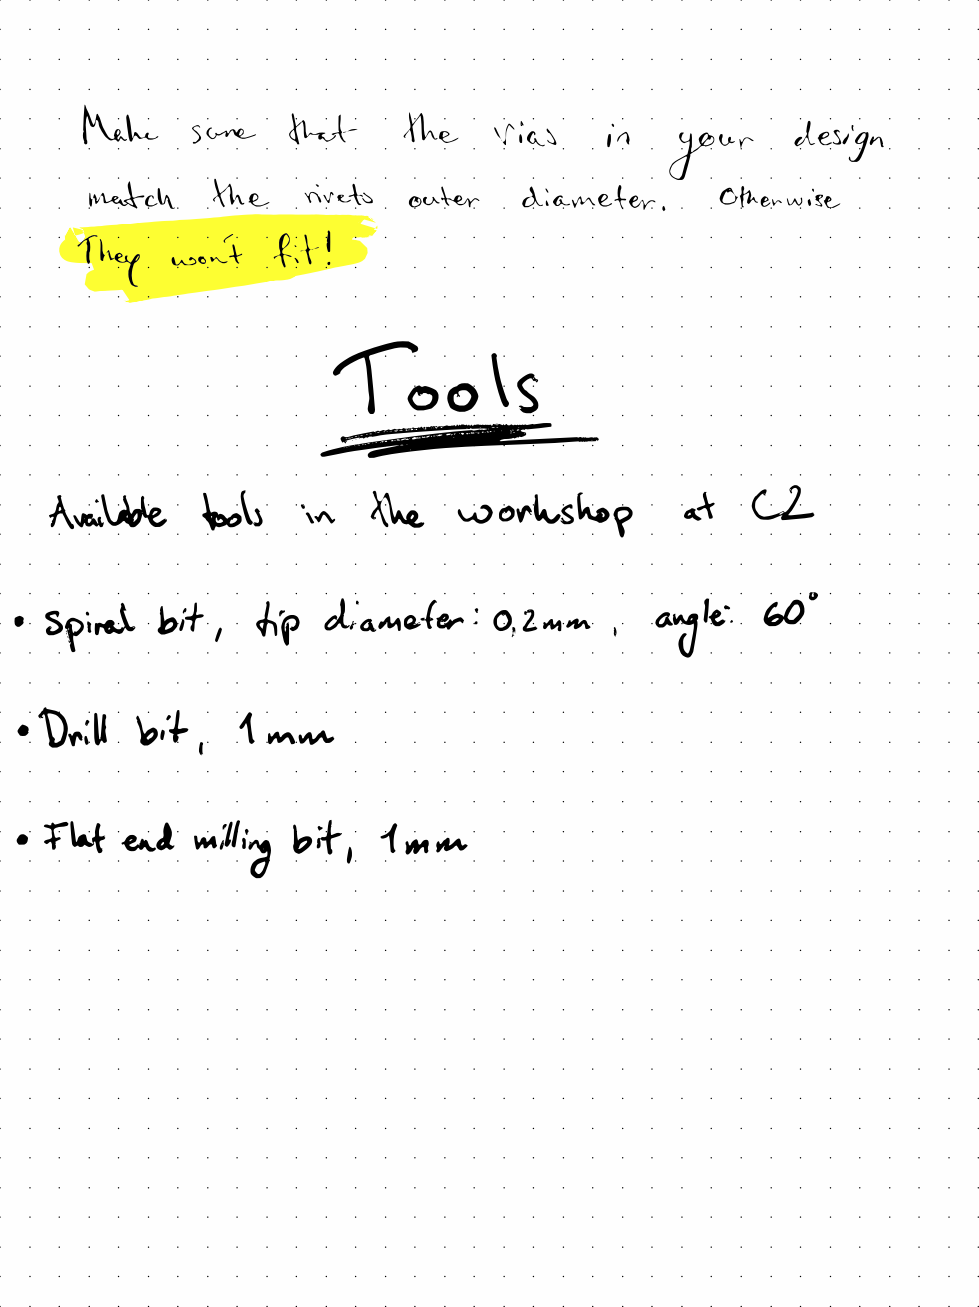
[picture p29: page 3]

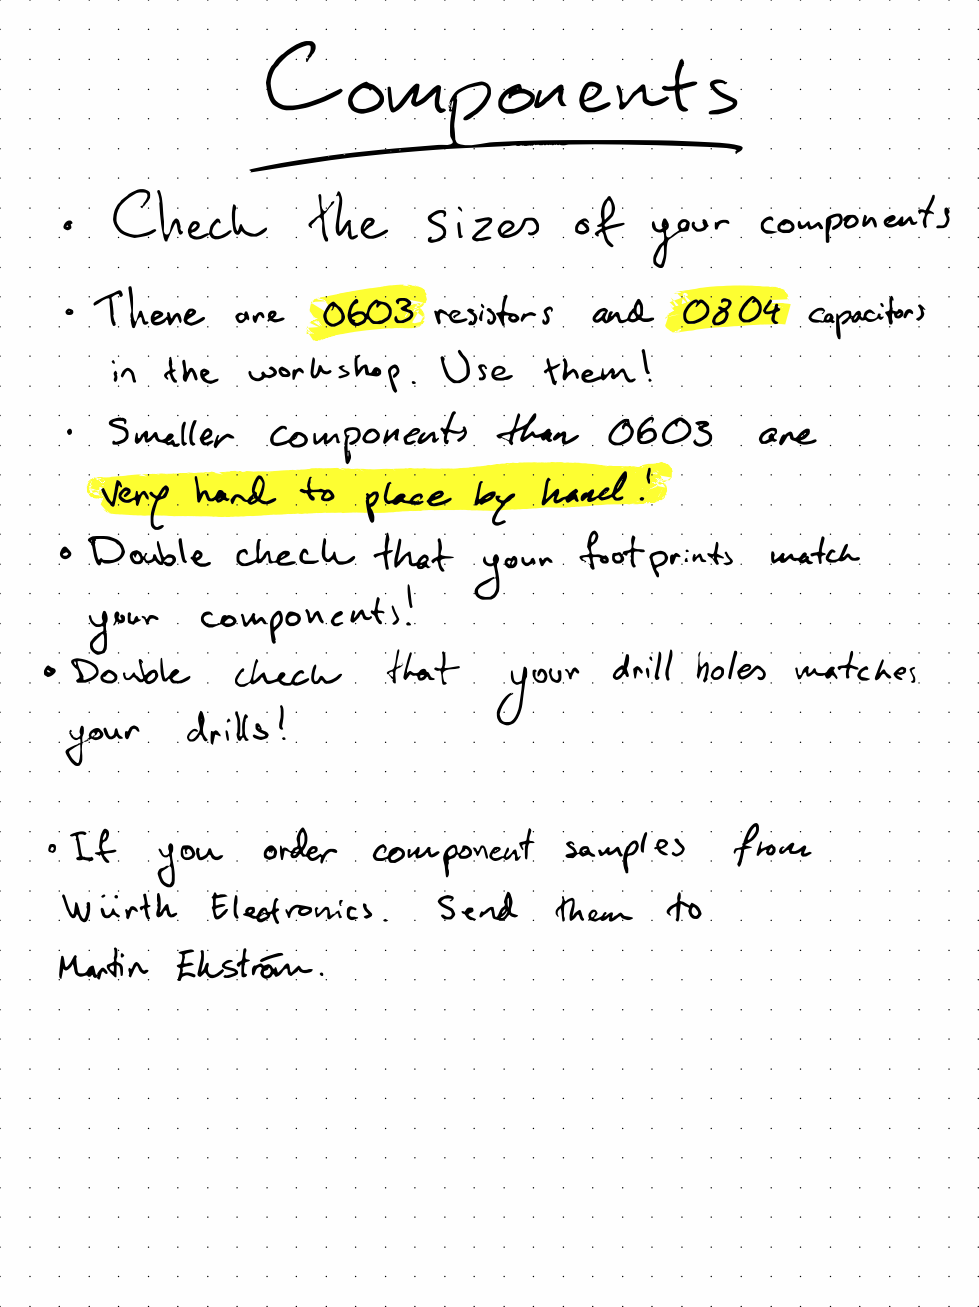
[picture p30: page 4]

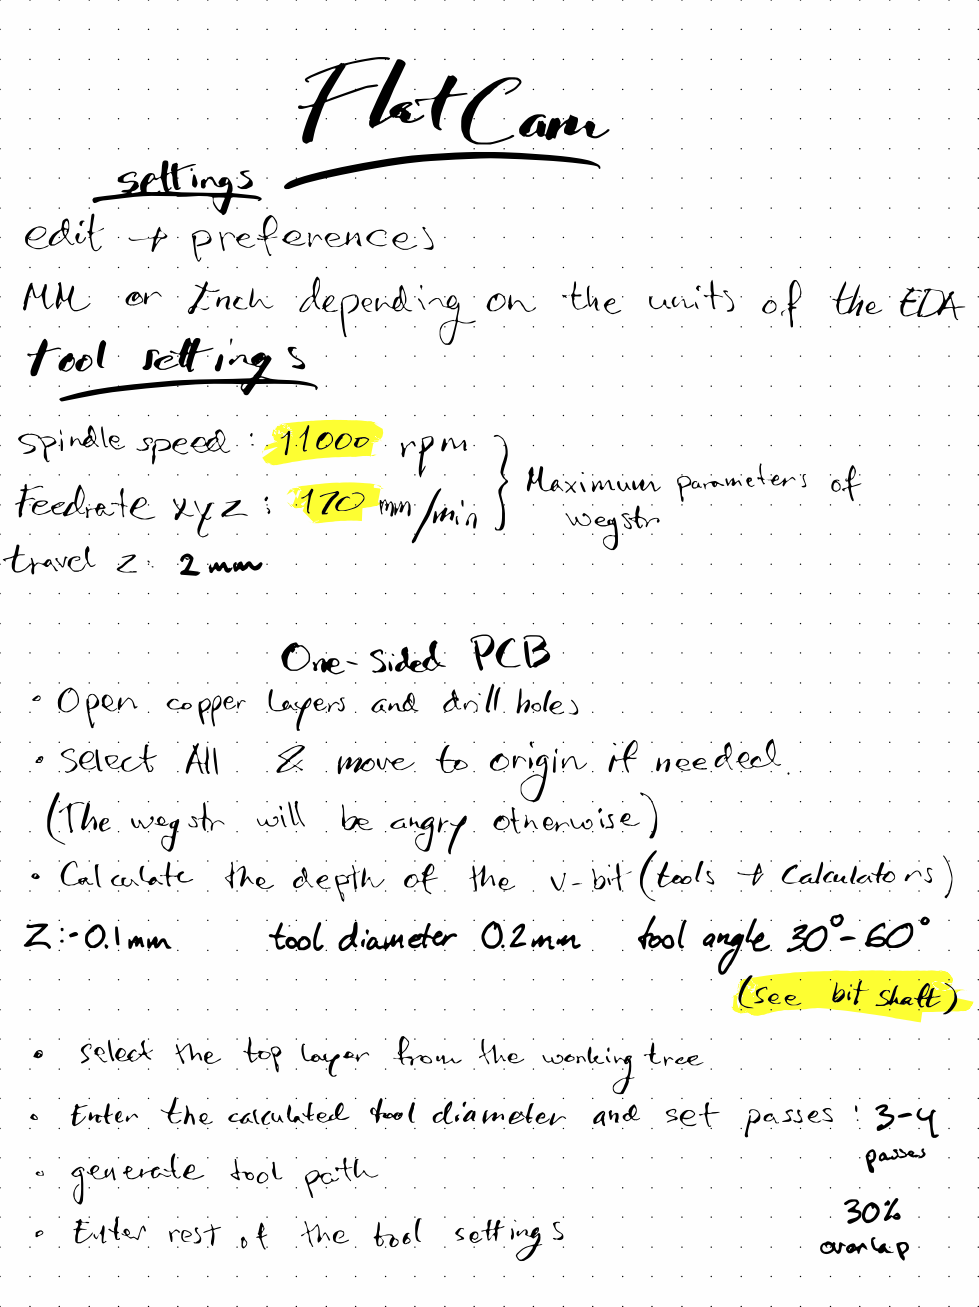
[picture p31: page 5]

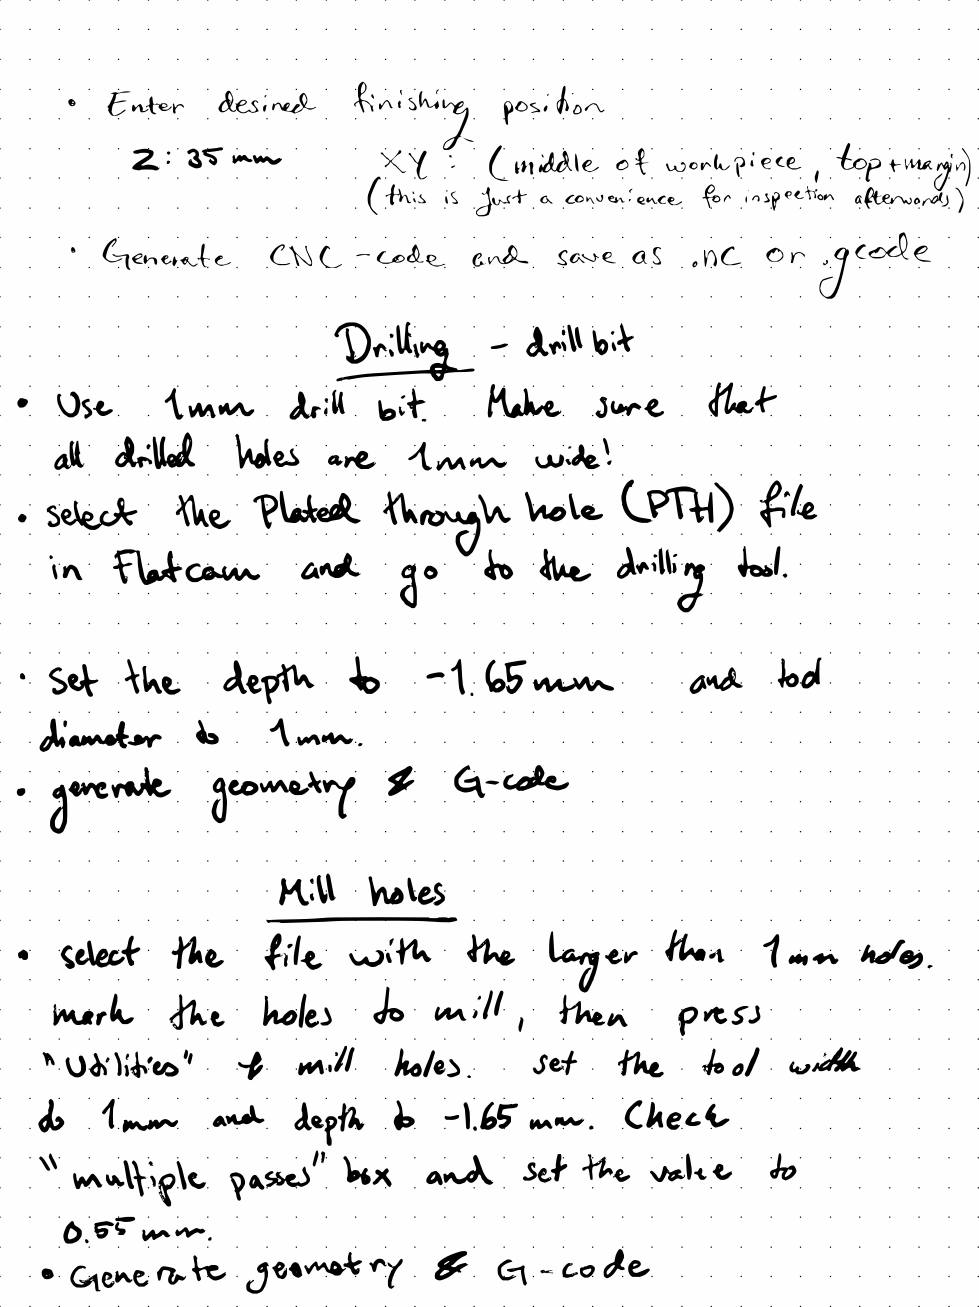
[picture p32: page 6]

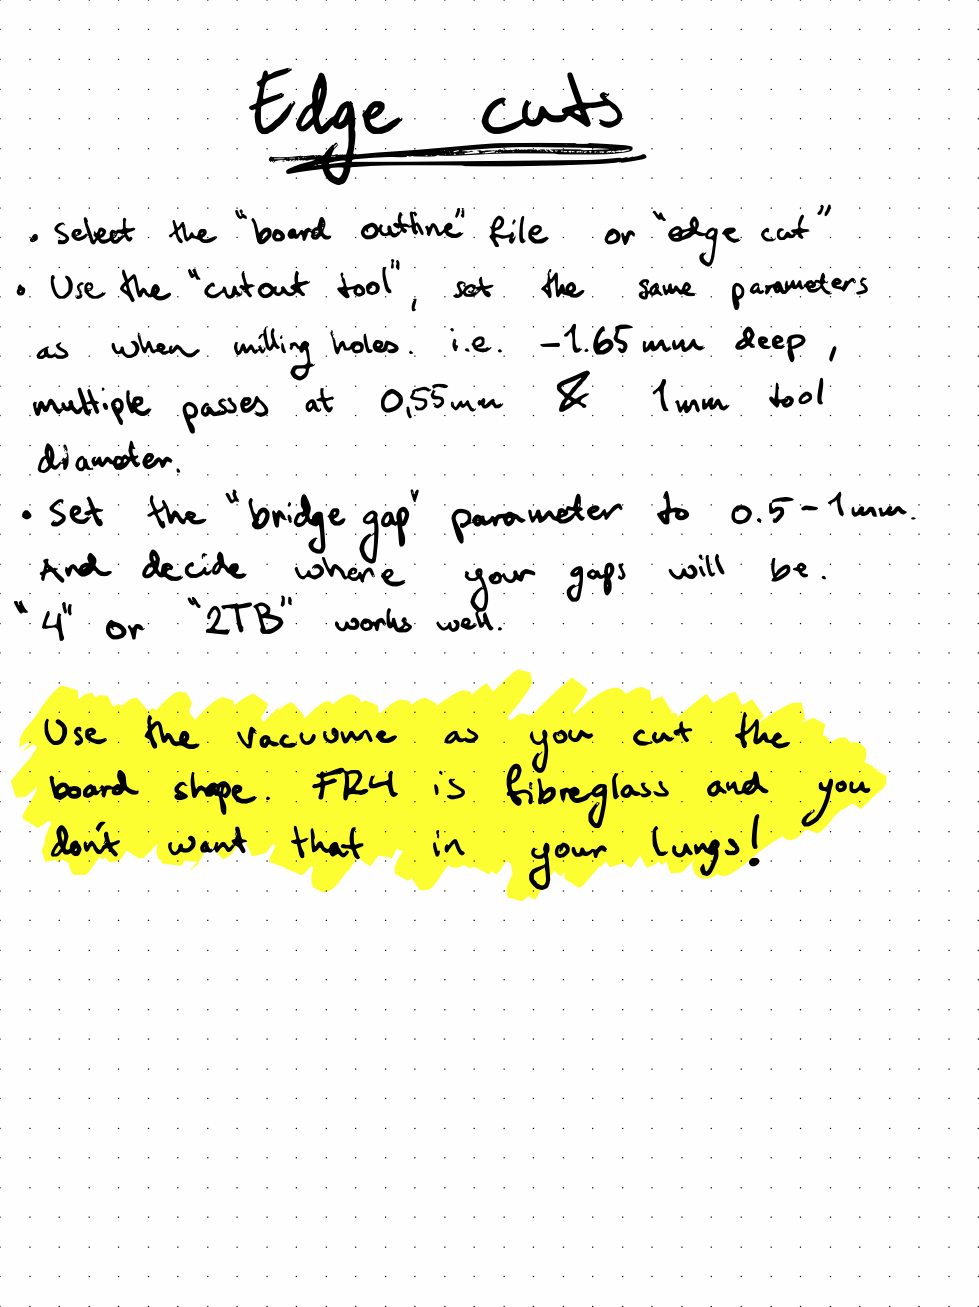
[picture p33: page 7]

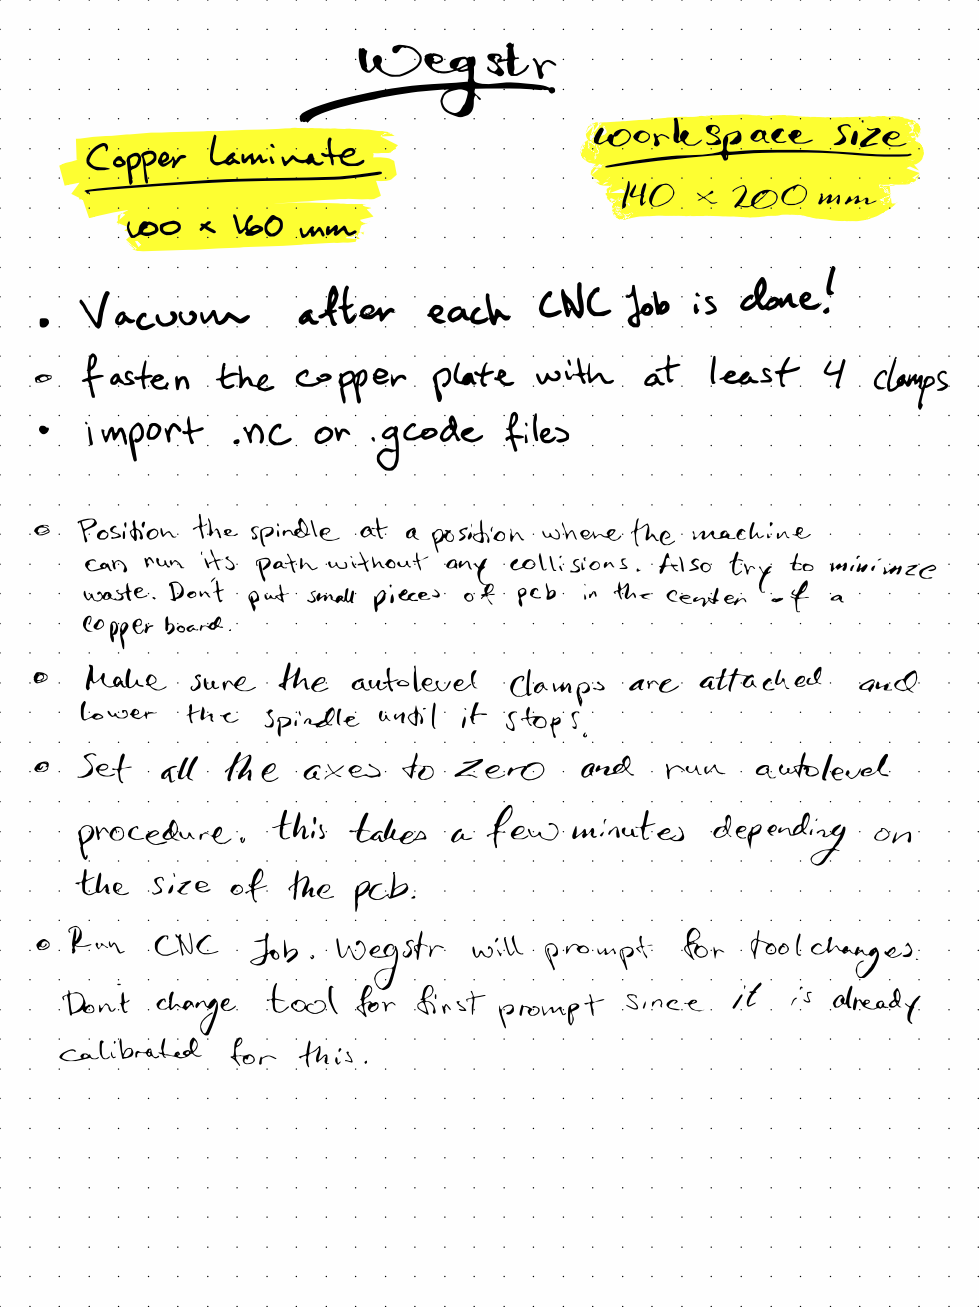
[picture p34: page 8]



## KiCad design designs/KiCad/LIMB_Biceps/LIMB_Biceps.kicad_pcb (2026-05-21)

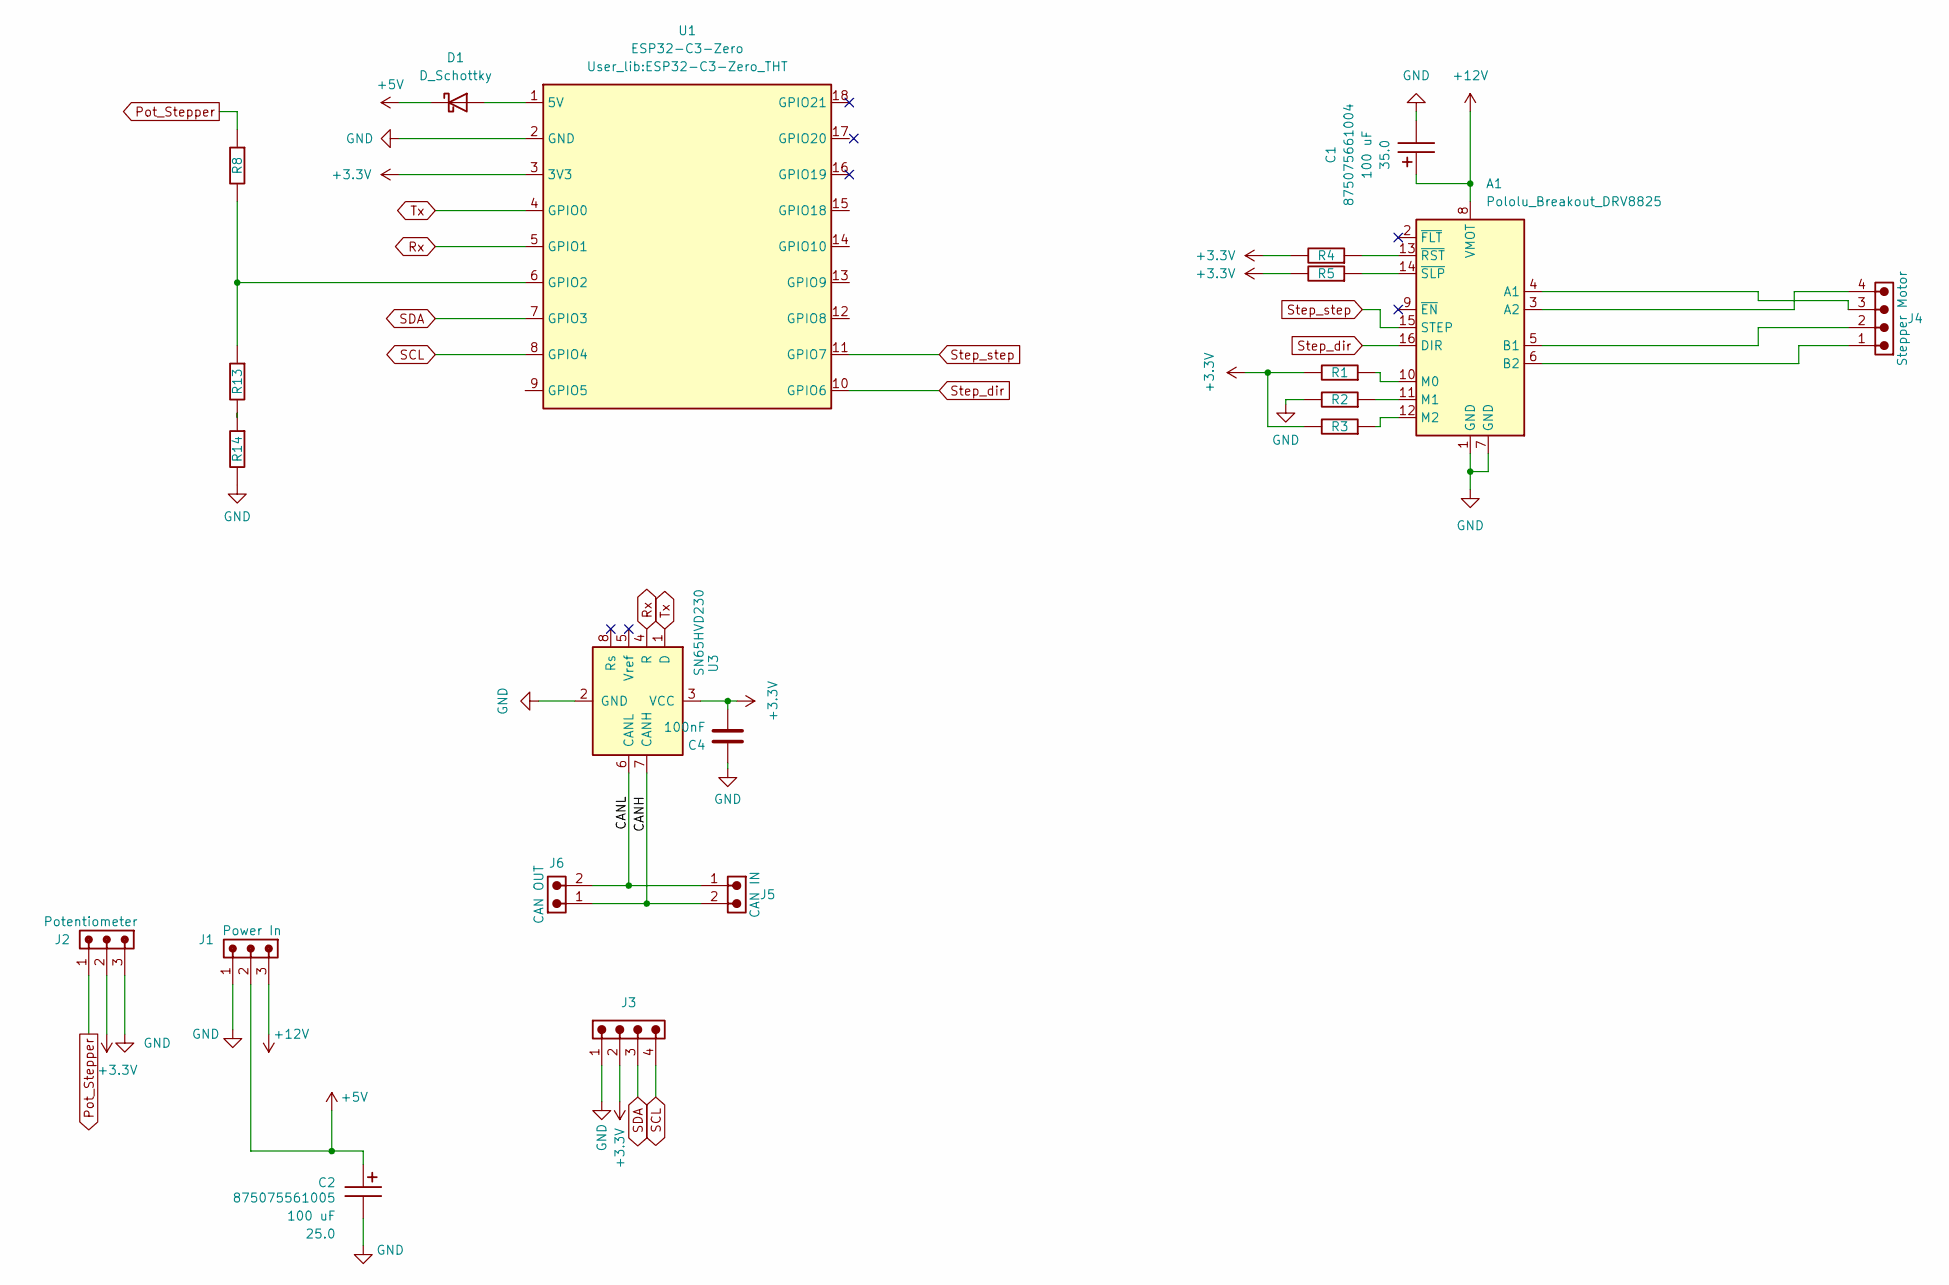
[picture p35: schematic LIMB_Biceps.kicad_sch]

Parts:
A1: Pololu_Breakout_DRV8825; Pololu_Breakout-16_15.2x20.3mm
C1: 100 uF; CP_Wurth_WCAP-ASLL-D6.3L5.5; Voltage 35.0; Part Number 875075661004
C2: 100 uF; CP_Wurth_WCAP-ASLL-D6.3L5.5; Voltage 25.0; Part Number 875075561005
C4: 100nF; C_0805_2012Metric_Pad1.18x1.45mm_HandSolder
D1: D_Schottky; D_SMA
J1: Power In; J_Wurth_WR-NPC2_626003110201; Part Number 626003110201
J2: Potentiometer; J_Wurth_WR-NPC2_626003110201; Part Number 626003110201
J3: IMU; J_Wurth_WR-WTB_68800411722; Working Voltage (V (AC)) 250
J4: Stepper Motor; J_Wurth_WR-WTB_68800411722; Working Voltage (V (AC)) 250
J5: CAN IN; J_Wurth_WR-WTB_68800211622; Working Voltage (V (AC)) 250
J6: CAN OUT; J_Wurth_WR-WTB_68800211622; Working Voltage (V (AC)) 250
R1, R2, R3, R4, R5, R8, R13, R14: 10K; R_0805_2012Metric
U1: ESP32-C3-Zero; ESP32-C3-Zero_THT
U3: SN65HVD230; SOIC-8_3.9x4.9mm_P1.27mm

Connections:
+3.3V: C4.2, J2.2, J3.2, R1.1, R3.1, R4.1, R5.1, U1.3 (3V3), U3.3 (VCC)
+5V: C2.1, D1.1 (K), J1.2
+12V: A1.8 (VMOT), C1.1, J1.3
/CANH: J5.2, J6.1, U3.7 (CANH)
/CANL: J5.1, J6.2, U3.6 (CANL)
GND: A1.1 (GND), A1.7 (GND), C1.2, C2.2, C4.1, J1.1, J2.3, J3.1, R2.1, R14.1, U1.2 (GND), U3.2 (GND)
unnamed: A1.4 (A1), J4.3
unnamed: A1.3 (A2), J4.4
unnamed: A1.5 (B1), J4.2
unnamed: A1.6 (B2), J4.1
unnamed: A1.10 (M0), R1.2
unnamed: A1.11 (M1), R2.2
unnamed: A1.12 (M2), R3.2
unnamed: A1.13 (~RST), R4.2
unnamed: A1.14 (~SLP), R5.2
unnamed: D1.2 (A), U1.1 (5V)
unnamed: R13.1, R14.2
unnamed: R8.1, R13.2, U1.6 (GPIO2)
Pot_Stepper: J2.1, R8.2
Rx: U1.5 (GPIO1), U3.4 (R)
SCL: J3.4, U1.8 (GPIO4)
SDA: J3.3, U1.7 (GPIO3)
Step_dir: A1.16 (DIR), U1.10 (GPIO6)
Step_step: A1.15 (STEP), U1.11 (GPIO7)
Tx: U1.4 (GPIO0), U3.1 (D)

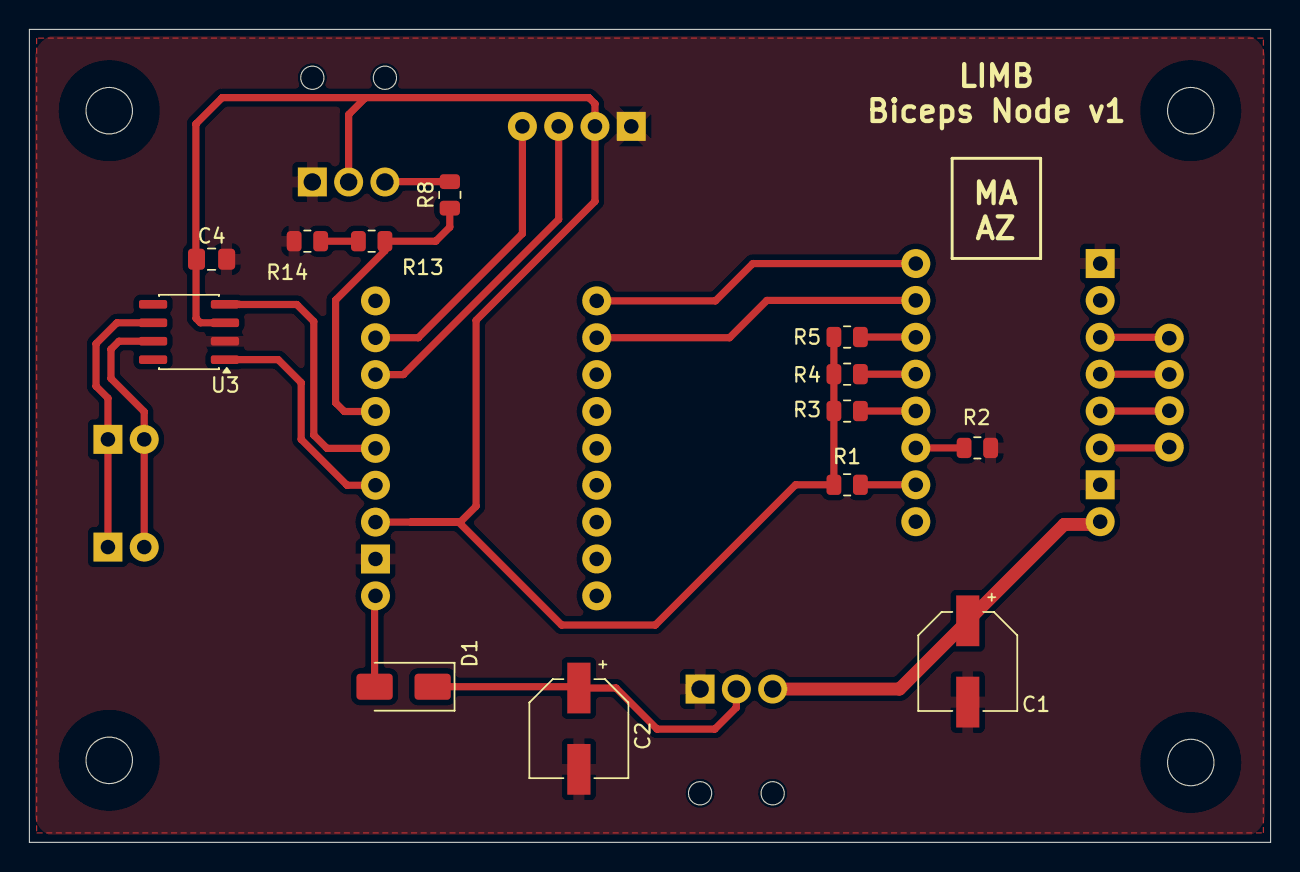
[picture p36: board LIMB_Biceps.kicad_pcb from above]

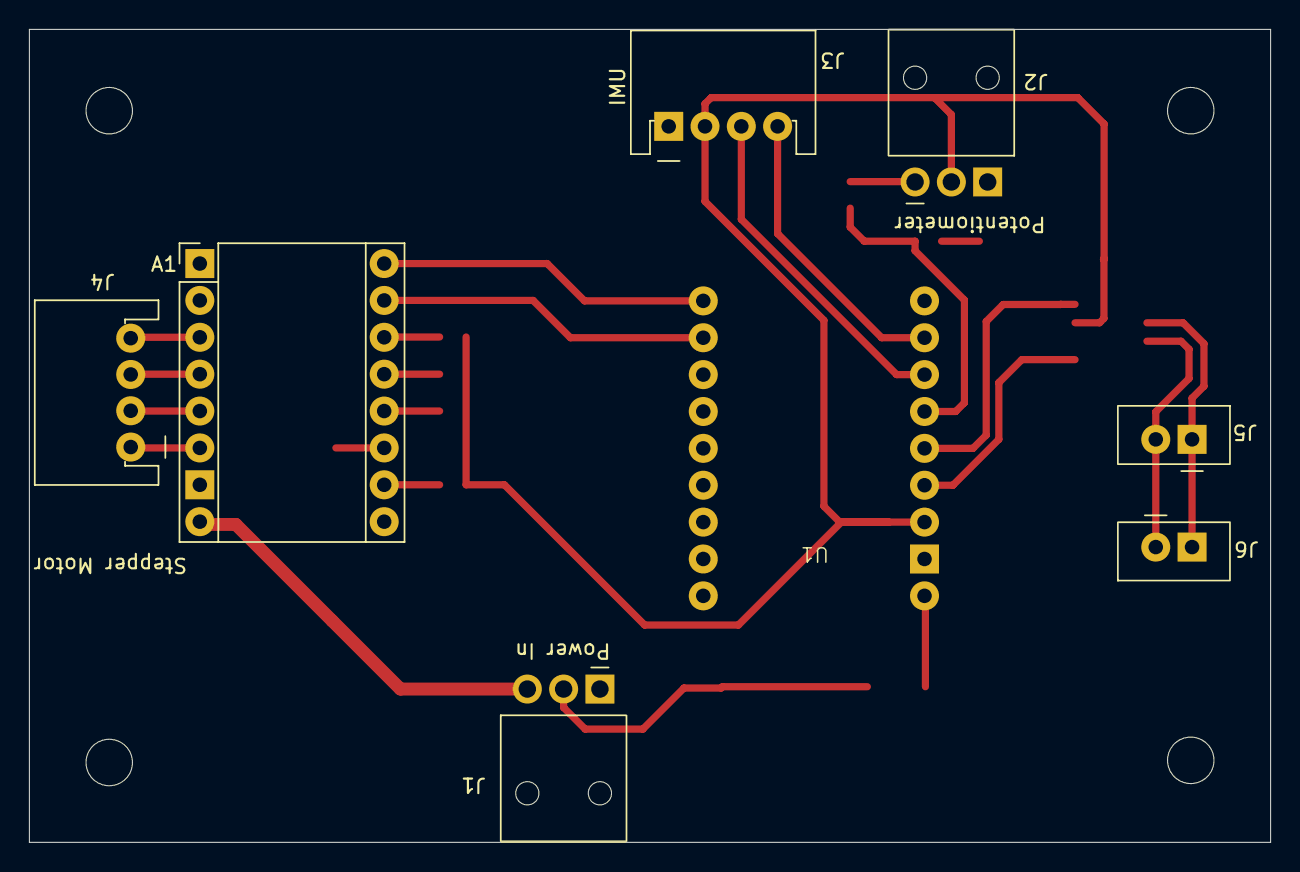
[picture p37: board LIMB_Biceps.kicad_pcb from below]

Board: 2 copper layers, 85.5 x 56.0 mm, 21 parts (8 on the bottom side), 25 nets.

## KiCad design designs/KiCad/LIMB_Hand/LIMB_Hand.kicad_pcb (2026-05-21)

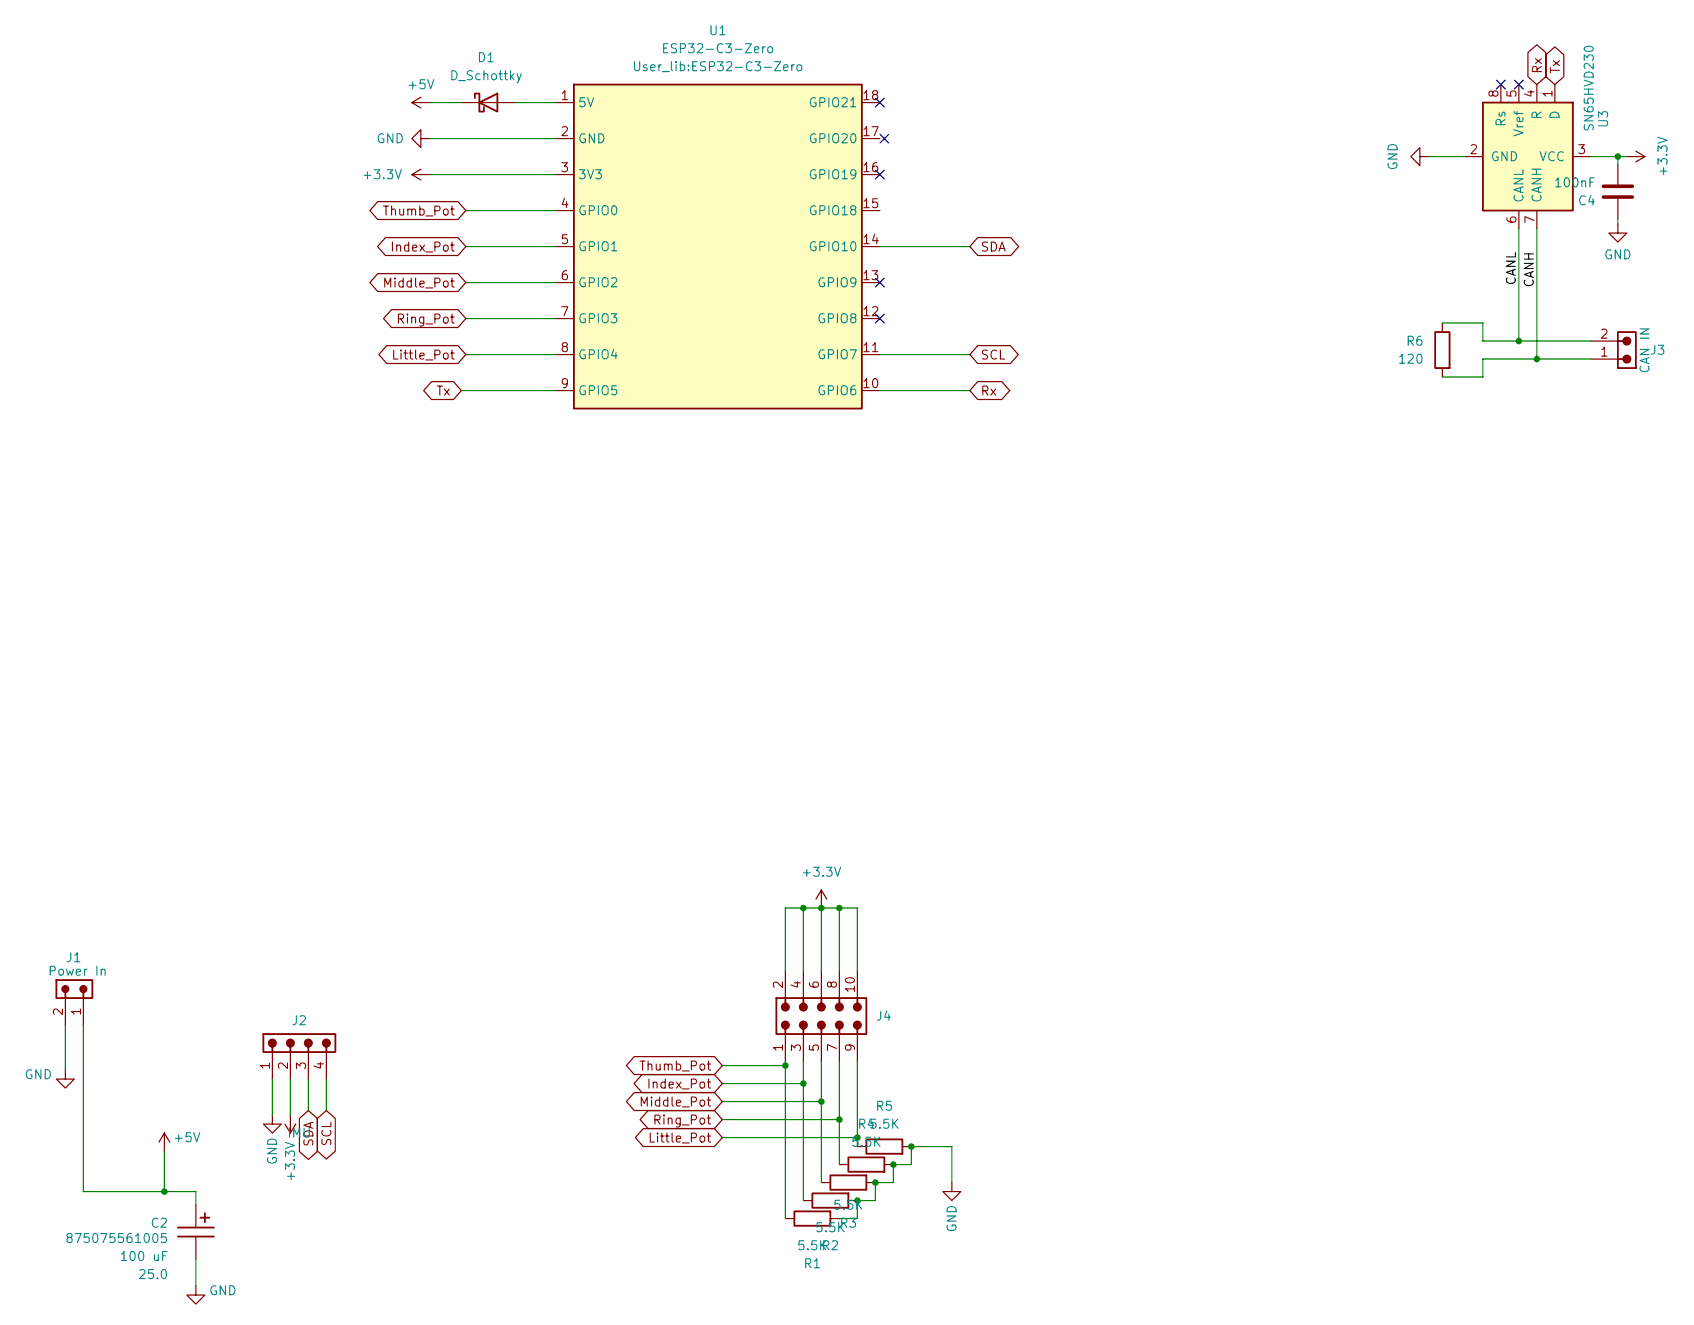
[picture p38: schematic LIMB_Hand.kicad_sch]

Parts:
C2: 100 uF; CP_Wurth_WCAP-ASLL-D6.3L5.5; Voltage 25.0; Part Number 875075561005
C4: 100nF; C_0805_2012Metric_Pad1.18x1.45mm_HandSolder
D1: D_Schottky; D_SMA
J1: Power In; J_Wurth_WR-NPC2_626002110201; Part Number 626002110201
J2: IMU; J_Wurth_WR-WTB_68800411622; Working Voltage (V (AC)) 250
J3: CAN IN; J_Wurth_WR-WTB_68800211622; Working Voltage (V (AC)) 250
J4: 61301021121; J_Wurth_WR-PHD_61301021121
R1, R2, R3, R4, R5: 5.5K; R_0805_2012Metric
R6: 120; R_0805_2012Metric
U1: ESP32-C3-Zero
U3: SN65HVD230; SOIC-8_3.9x4.9mm_P1.27mm

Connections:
+3.3V: C4.2, J2.2, J4.2, J4.4, J4.6, J4.8, J4.10, U1.3 (3V3), U3.3 (VCC)
+5V: C2.1, D1.1 (K), J1.1
/CANH: J3.1, R6.2, U3.7 (CANH)
/CANL: J3.2, R6.1, U3.6 (CANL)
GND: C2.2, C4.1, J1.2, J2.1, R1.2, R2.2, R3.2, R4.2, R5.2, U1.2 (GND), U3.2 (GND)
Index_Pot: J4.3, R2.1, U1.5 (GPIO1)
Little_Pot: J4.9, R5.1, U1.8 (GPIO4)
Middle_Pot: J4.5, R3.1, U1.6 (GPIO2)
unnamed: D1.2 (A), U1.1 (5V)
Ring_Pot: J4.7, R4.1, U1.7 (GPIO3)
Rx: U1.10 (GPIO6), U3.4 (R)
SCL: J2.4, U1.11 (GPIO7)
SDA: J2.3, U1.14 (GPIO10)
Thumb_Pot: J4.1, R1.1, U1.4 (GPIO0)
Tx: U1.9 (GPIO5), U3.1 (D)

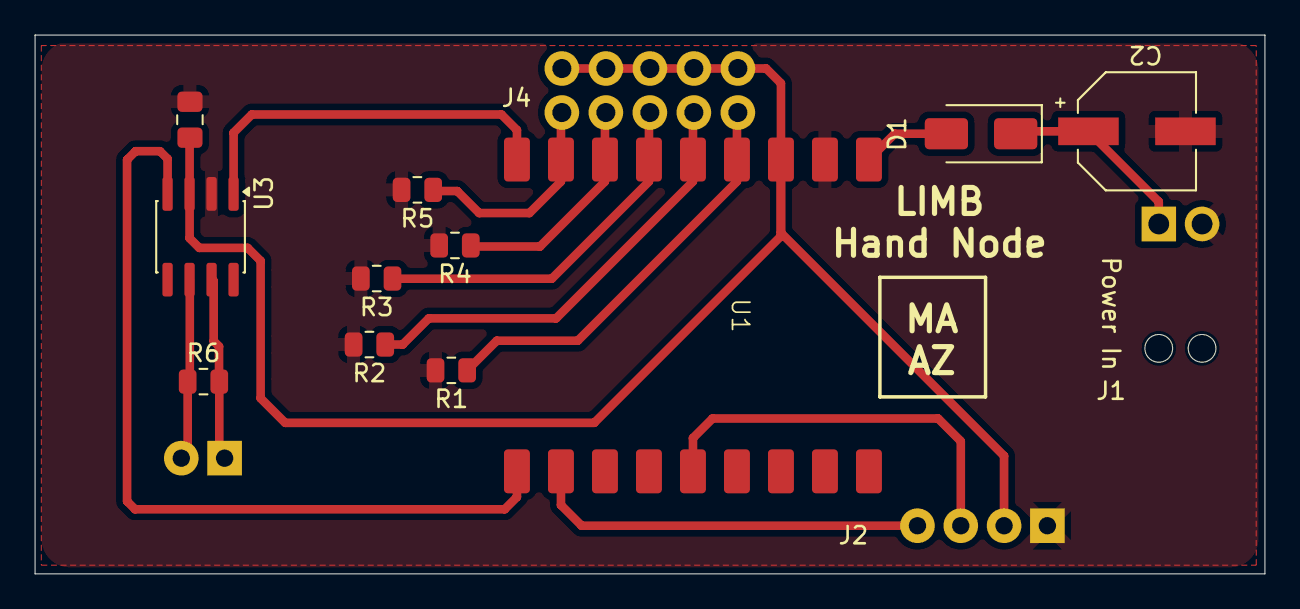
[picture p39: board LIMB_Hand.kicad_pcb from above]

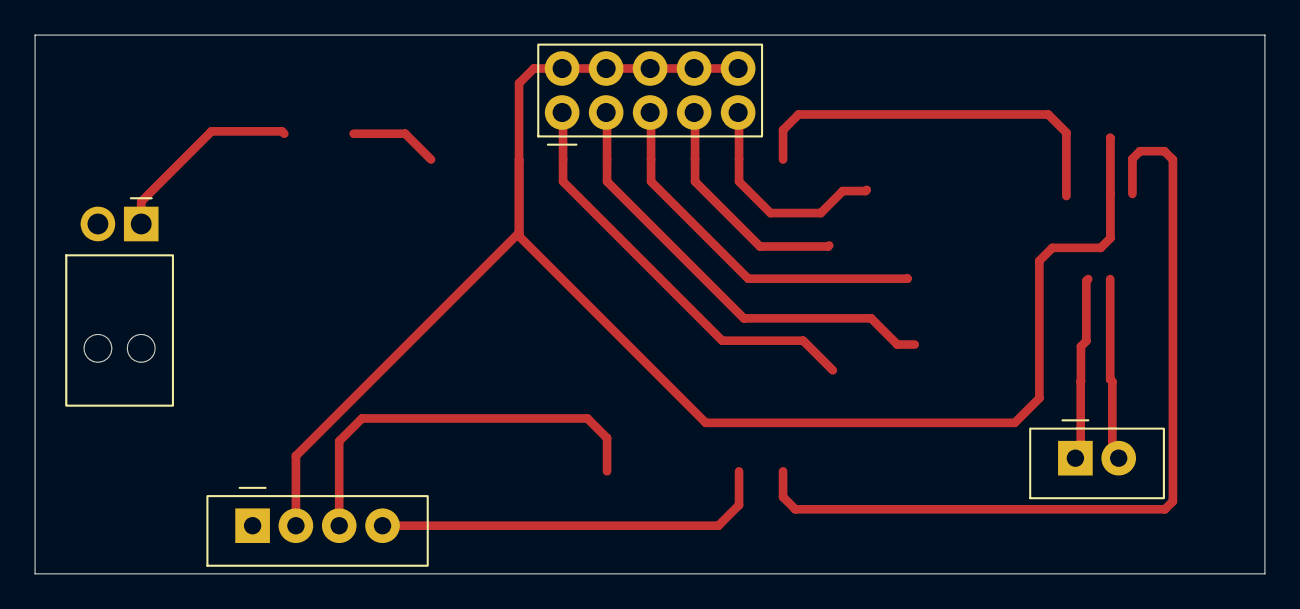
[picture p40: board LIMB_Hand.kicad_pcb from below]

Board: 2 copper layers, 71.0 x 31.1 mm, 15 parts (4 on the bottom side), 15 nets.

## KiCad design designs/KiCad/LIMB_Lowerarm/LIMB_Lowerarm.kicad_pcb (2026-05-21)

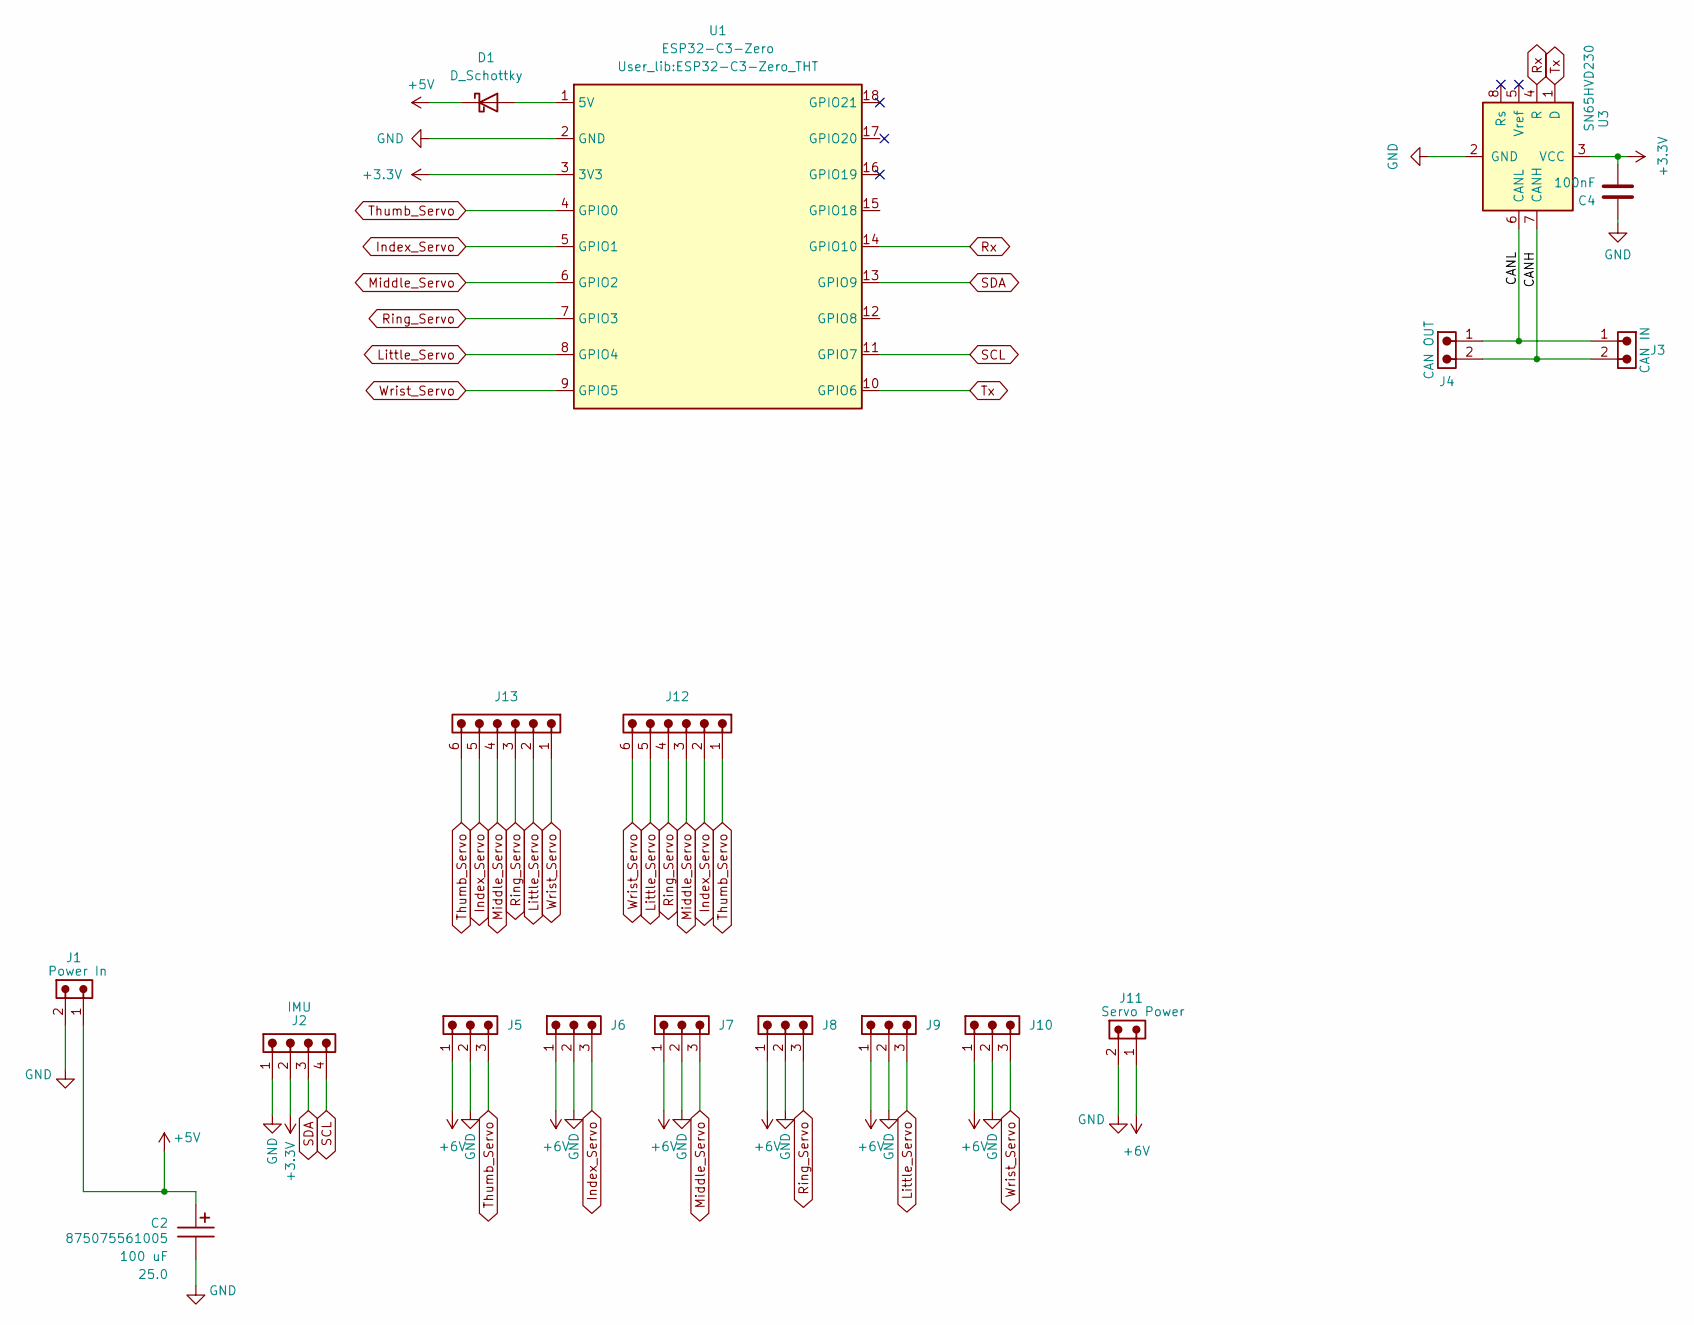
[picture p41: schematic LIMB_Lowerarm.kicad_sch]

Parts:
C2: 100 uF; CP_Wurth_WCAP-ASLL-D6.3L5.5; Voltage 25.0; Part Number 875075561005
C4: 100nF; C_0805_2012Metric_Pad1.18x1.45mm_HandSolder
D1: D_Schottky; D_SMA
J1: Power In; J_Wurth_WR-NPC2_626002110201; Part Number 626002110201
J2: IMU; J_Wurth_WR-WTB_68800411622; Working Voltage (V (AC)) 250
J3: CAN IN; J_Wurth_WR-WTB_68800211622; Working Voltage (V (AC)) 250
J4: CAN OUT; J_Wurth_WR-WTB_68800211622; Working Voltage (V (AC)) 250
J5, J6, J7, J8, J9, J10: 68800311622; J_Wurth_WR-WTB_68800311622; Working Voltage (V (AC)) 250
J11: Servo Power; J_Wurth_WR-NPC2_626002110201; Part Number 626002110201
J12, J13: 68800611722; J_Wurth_WR-WTB_68800611722; Working Voltage (V (AC)) 250
U1: ESP32-C3-Zero; ESP32-C3-Zero_THT
U3: SN65HVD230; SOIC-8_3.9x4.9mm_P1.27mm

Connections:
+3.3V: C4.2, J2.2, U1.3 (3V3), U3.3 (VCC)
+5V: C2.1, D1.1 (K), J1.1
+6V: J5.1, J6.1, J7.1, J8.1, J9.1, J10.1, J11.1
/CANH: J3.2, J4.2, U3.7 (CANH)
/CANL: J3.1, J4.1, U3.6 (CANL)
GND: C2.2, C4.1, J1.2, J2.1, J5.2, J6.2, J7.2, J8.2, J9.2, J10.2, J11.2, U1.2 (GND), U3.2 (GND)
Index_Servo: J6.3, J12.2, J13.5, U1.5 (GPIO1)
Little_Servo: J9.3, J12.5, J13.2, U1.8 (GPIO4)
Middle_Servo: J7.3, J12.3, J13.4, U1.6 (GPIO2)
unnamed: D1.2 (A), U1.1 (5V)
Ring_Servo: J8.3, J12.4, J13.3, U1.7 (GPIO3)
Rx: U1.14 (GPIO10), U3.4 (R)
SCL: J2.4, U1.11 (GPIO7)
SDA: J2.3, U1.13 (GPIO9)
Thumb_Servo: J5.3, J12.1, J13.6, U1.4 (GPIO0)
Tx: U1.10 (GPIO6), U3.1 (D)
Wrist_Servo: J10.3, J12.6, J13.1, U1.9 (GPIO5)

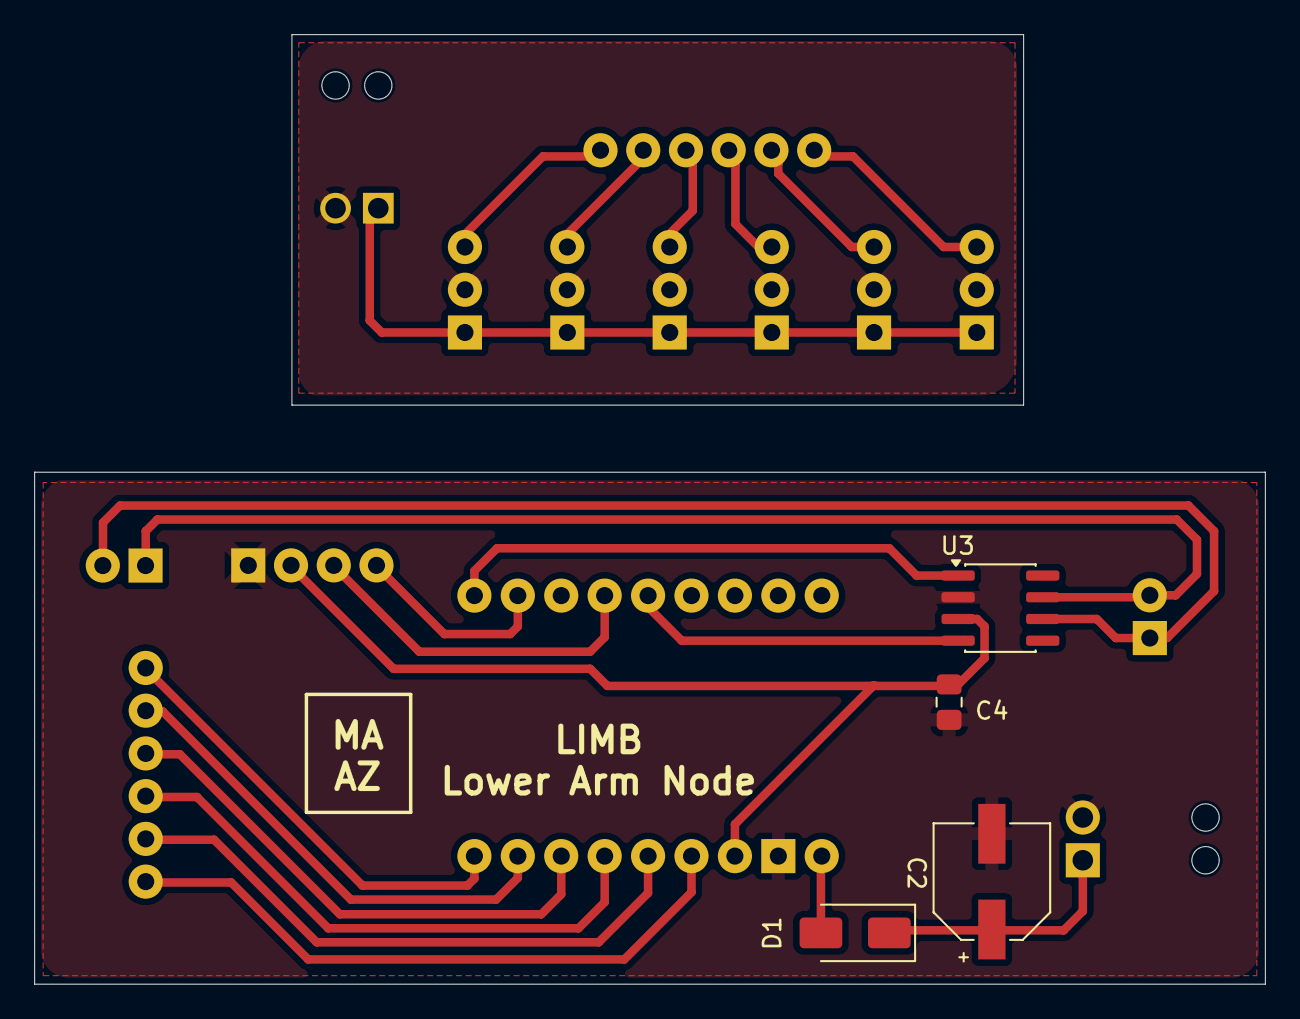
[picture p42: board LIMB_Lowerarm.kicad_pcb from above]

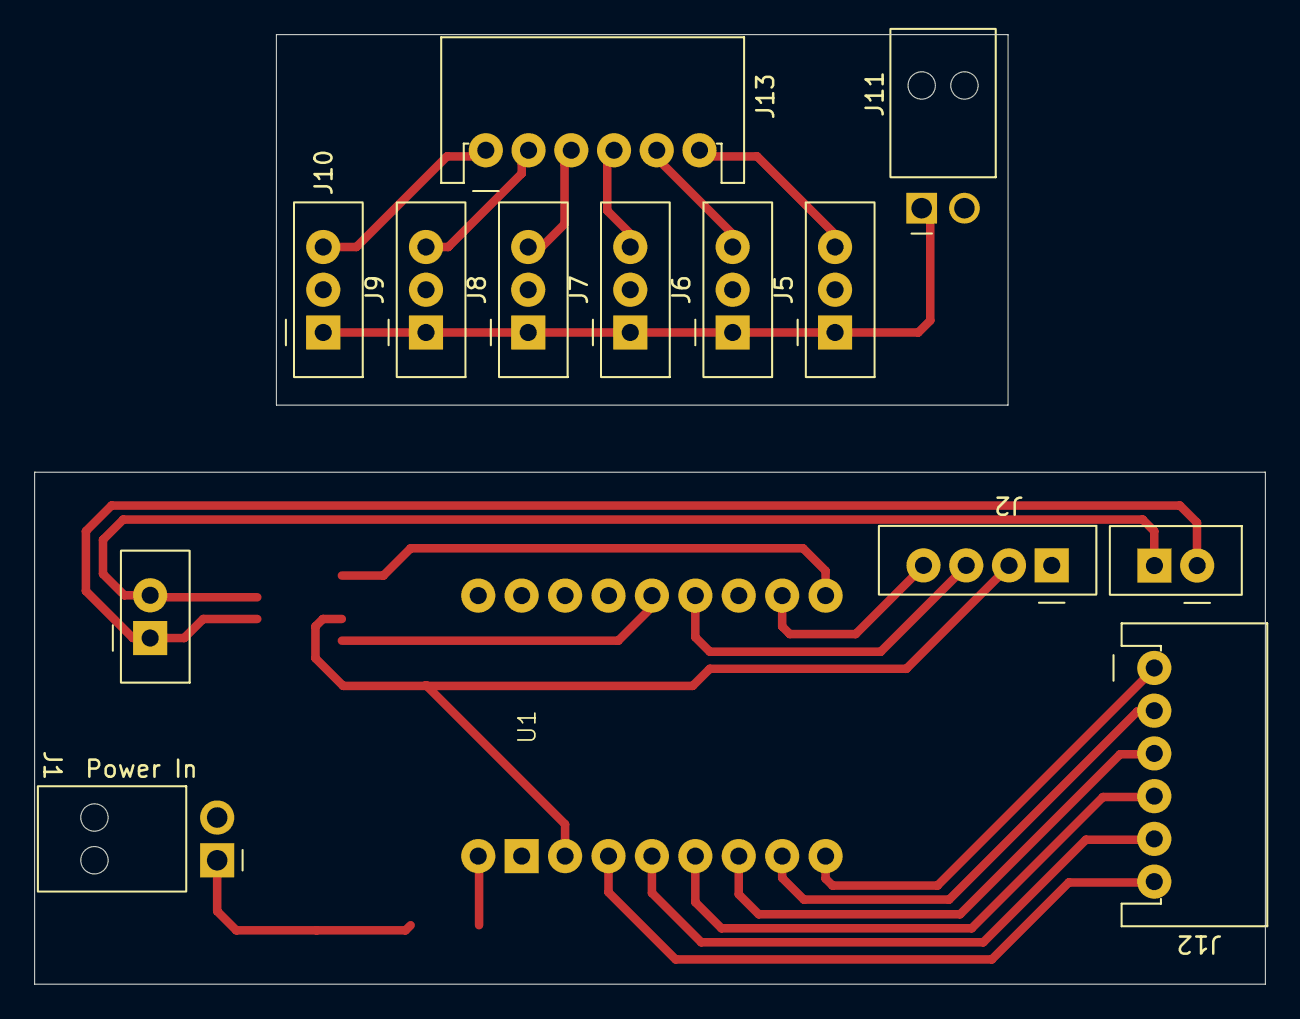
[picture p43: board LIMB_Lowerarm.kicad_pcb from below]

Board: 2 copper layers, 72.0 x 55.5 mm, 18 parts (14 on the bottom side), 17 nets.

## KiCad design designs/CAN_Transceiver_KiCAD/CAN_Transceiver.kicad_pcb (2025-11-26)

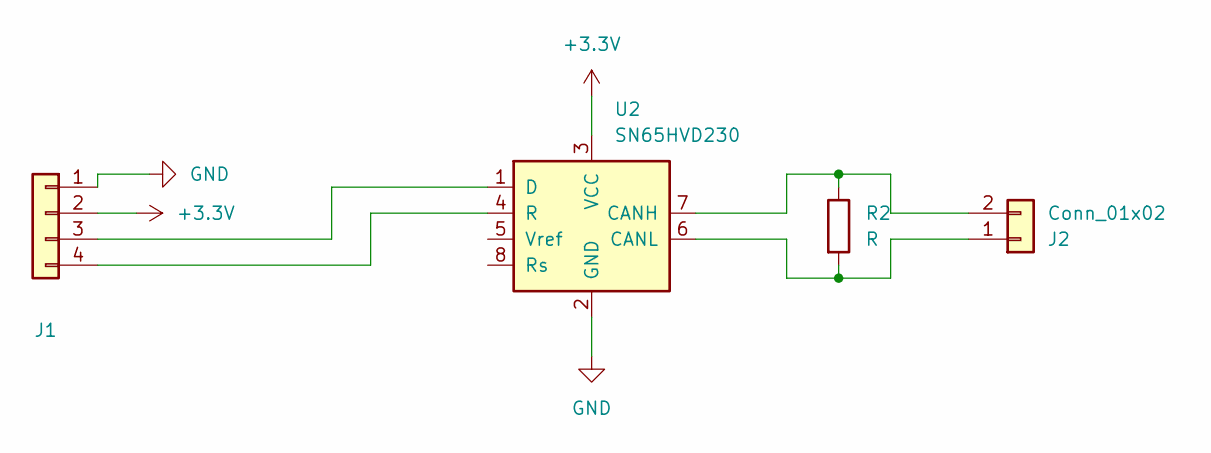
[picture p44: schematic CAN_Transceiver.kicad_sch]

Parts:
J1: Conn_01x04; PinHeader_1x04_P2.54mm_Vertical
J2: Conn_01x02; PinHeader_1x02_P2.54mm_Vertical
R2: R; R_0603_1608Metric_Pad0.98x0.95mm_HandSolder
U2: SN65HVD230; SOIC-8_3.9x4.9mm_P1.27mm

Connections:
+3.3V: J1.2, U2.3 (VCC)
GND: J1.1, U2.2 (GND)
unnamed: J1.3, U2.1 (D)
unnamed: J1.4, U2.4 (R)
unnamed: J2.1, R2.2, U2.6 (CANL)
unnamed: J2.2, R2.1, U2.7 (CANH)

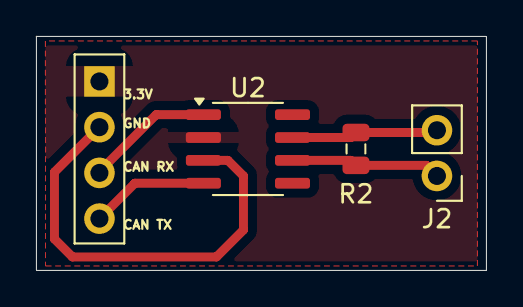
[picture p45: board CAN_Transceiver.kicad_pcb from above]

Board: 2 copper layers, 25.0 x 13.0 mm, 4 parts (0 on the bottom side), 6 nets.

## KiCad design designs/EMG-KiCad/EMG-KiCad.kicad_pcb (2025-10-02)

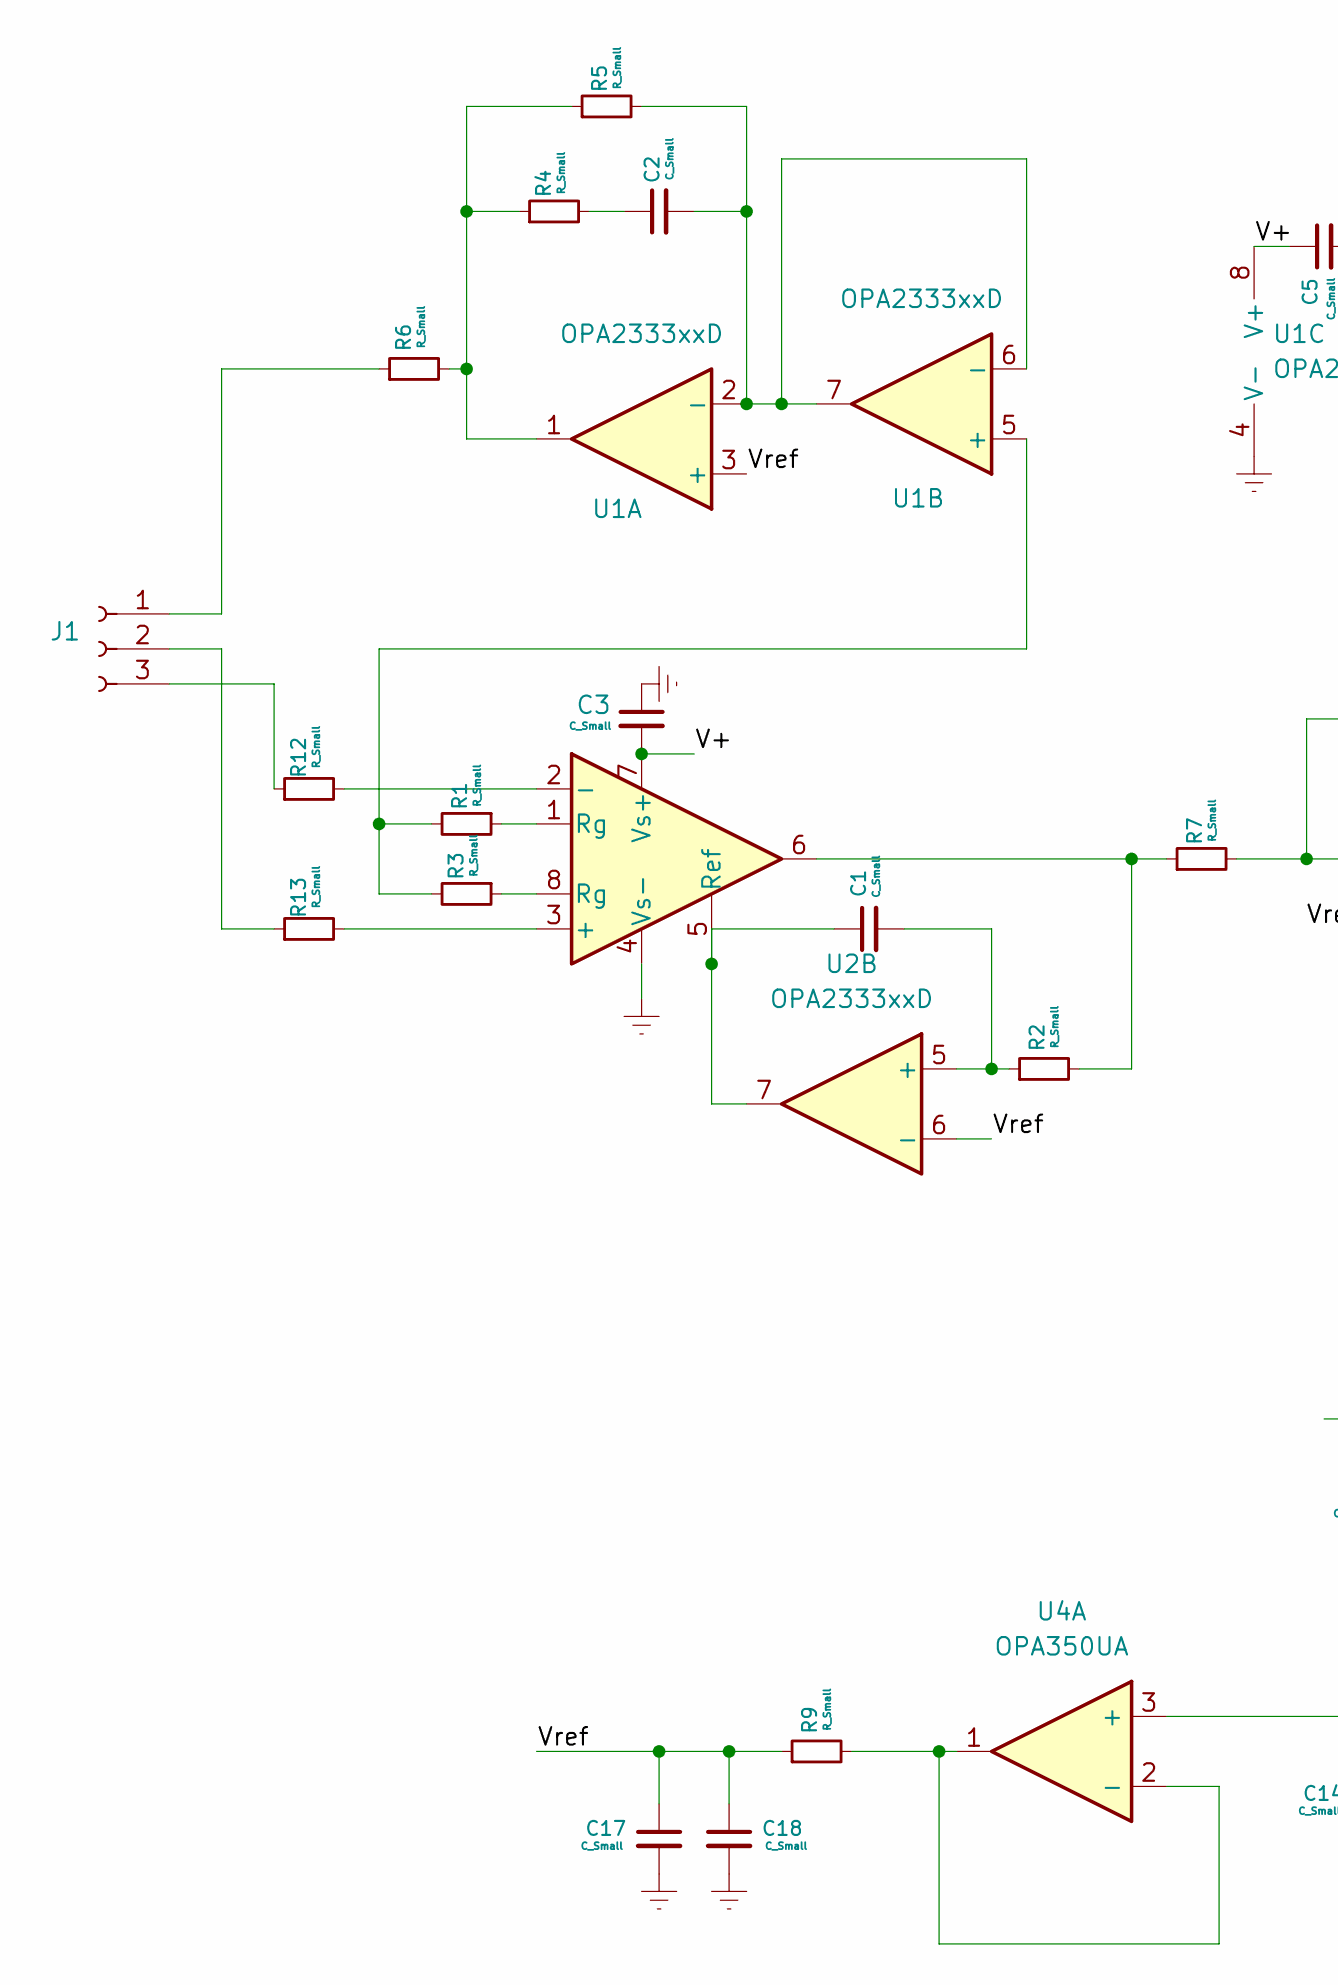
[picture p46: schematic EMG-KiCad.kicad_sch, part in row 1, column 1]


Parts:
C1, C2, C3, C4, C5, C7, C8, C9, C10, C11, C12, C13, C14, C15, C16, C17, C18, C19: C_Small; C_0603_1608Metric_Pad1.08x0.95mm_HandSolder
J1: Conn_01x03_Socket; Samtec_HPM-03-05-x-S_Straight_1x03_Pitch5.08mm
J3: Conn_01x02_Socket; Samtec_HPM-02-05-x-S_Straight_1x02_Pitch5.08mm
J4: Conn_01x01_Socket; Samtec_HPM-01-05-x-S_Straight_1x01_Pitch5.08mm
R1, R2, R3, R4, R5, R6, R7, R8, R9, R10, R12, R13, R14, R15, R16: R_Small; R_0603_1608Metric_Pad0.98x0.95mm_HandSolder
R11: 3314J-1-103E; POT_3314J
U0: AD623; SOIC-8_5.3x6.2mm_P1.27mm
U1, U2: OPA2333xxD; SOIC-8_3.9x4.9mm_P1.27mm
U3: OPA333xxDBV; SOT-23-5
U4: OPA350UA; SOIC-8_5.3x6.2mm_P1.27mm
U5: LDO 3.3; SOT-23-5
U6: LDO 1.5; SOT-23-5

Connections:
/V+: C3.2, C5.1, C7.1, C9.1, C12.1, C16.2, C19.2, R15.2, U0.7 (Vs+), U1.8 (V+), U2.8 (V+), U3.5 (V+), U4.8 (V+)
/Vout: C4.2, J4.1, R10.2, U3.1
/Vpower: C8.1, C10.1, C11.1, C13.1, J3.1, U5.1 (IN), U6.1 (IN)
/Vref: C17.1, C18.1, R9.1, U1.3 (+), U2.3 (+), U2.6 (-), U3.3 (+)
Earth: C3.1, C5.2, C7.2, C8.2, C9.2, C10.2, C11.2, C12.2, C13.2, C14.2, C15.2, C16.1, C17.2, C18.2, C19.1, J3.2, R11.3, U0.4 (Vs-), U1.4 (V-), U2.4 (V-), U3.2 (V-), U4.4 (V-), U5.2 (GND), U6.2 (GND)
unnamed: C2.1, R4.2
unnamed: J1.1, R6.1
unnamed: J1.2, R13.1
unnamed: J1.3, R12.1
unnamed: R1.1, U0.1 (Rg)
unnamed: R2.2, R7.1, U0.6
unnamed: R3.1, U0.8 (Rg)
unnamed: R4.1, R5.1, R6.2, U1.1
unnamed: R8.1, R11.1, U2.1
unnamed: R11.2, R14.2
unnamed: R13.2, U0.3 (+)
unnamed: R12.2, U0.2 (-)
unnamed: C1.1, U0.5 (Ref), U2.7
unnamed: C2.2, R5.2, U1.2 (-), U1.6 (-), U1.7
unnamed: R1.2, R3.2, U1.5 (+)
unnamed: R7.2, R8.2, U2.2 (-)
unnamed: C1.2, R2.1, U2.5 (+)
unnamed: C4.1, R10.1, R14.1, U3.4 (-)
unnamed: C14.1, C15.1, R16.2, U4.3 (+)
unnamed: R9.2, U4.1, U4.2 (-)
unnamed: R15.1, U5.5 (OUT)
unnamed: R16.1, U6.5 (OUT)


Board: 2 copper layers, 44 parts (0 on the bottom side), 27 nets.

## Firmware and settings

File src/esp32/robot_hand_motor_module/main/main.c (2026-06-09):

#include "can_driver.h"
#include "esp_err.h"
#include "esp_log.h"
#include "freertos/FreeRTOS.h"
#include "freertos/idf_additions.h"
#include "freertos/projdefs.h"
#include "freertos/task.h"
#include "imu.h"
#include "limb_utils.h"
#include "portmacro.h"
#include "servo.h"

static const char* TAG = "Hand motor module";

enum {
  CAN_TX_PIN = GPIO_NUM_6,
  CAN_RX_PIN = GPIO_NUM_10,
  CAN_BAUDRATE = 1000000,

  IMU_SDA_GPIO = GPIO_NUM_9,
  IMU_SCL_GPIO = GPIO_NUM_7,

  THUMB_CONFIG_INDEX = 0,
  INDEX_CONFIG_INDEX = 1,
  MIDDLE_CONFIG_INDEX = 2,
  RING_CONFIG_INDEX = 3,
  PINKY_CONFIG_INDEX = 4,
  WRIST_CONFIG_INDEX = 5,

  THUMB_SERVO_GPIO = GPIO_NUM_0,
  INDEX_SERVO_GPIO = GPIO_NUM_1,
  MID_SERVO_GPIO = GPIO_NUM_2,
  RING_SERVO_GPIO = GPIO_NUM_3,
  PINKY_SERVO_GPIO = GPIO_NUM_4,
  TWIST_SERVO_GPIO = GPIO_NUM_5,
};

// Servo configurations - customize each servo individually
static const servo_config_t s_servo_configs[] = {
    // Thumb servo
    [THUMB_CONFIG_INDEX] = {.gpio_pin = THUMB_SERVO_GPIO,
                            .ledc_channel = LEDC_CHANNEL_0,
                            .max_angle = 30,
                            .min_angle = 0,
                            .min_pulse_us = 1400,
                            .max_pulse_us = 1900,
                            .max_speed = {40},
                            .direction = SERVO_DIR_REVERSE,
                            .name = "Thumb"},
    // Index finger
    [INDEX_CONFIG_INDEX] = {.gpio_pin = INDEX_SERVO_GPIO,
                            .ledc_channel = LEDC_CHANNEL_1,
                            .max_angle = 85,
                            .min_angle = 0,
                            .min_pulse_us = 1100,
                            .max_pulse_us = 1900,
                            .max_speed = {40},
                            .direction = SERVO_DIR_REVERSE,
                            .name = "Index"},
    // Middle finger
    [MIDDLE_CONFIG_INDEX] = {.gpio_pin = MID_SERVO_GPIO,
                             .ledc_channel = LEDC_CHANNEL_2,
                             .max_angle = 90,
                             .min_angle = 0,
                             .min_pulse_us = 800,
                             .max_pulse_us = 1700,
                             .max_speed = {40},
                             .direction = SERVO_DIR_REVERSE,
                             .name = "Middle"},
    // Ring finger
    [RING_CONFIG_INDEX] = {.gpio_pin = RING_SERVO_GPIO,
                           .ledc_channel = LEDC_CHANNEL_3,
                           .max_angle = 50,
                           .min_angle = 0,
                           .min_pulse_us = 1400,
                           .max_pulse_us = 2200,
                           .max_speed = {40},
                           .direction = SERVO_DIR_REVERSE,
                           .name = "Ring"},
    // Pinky finger
    [PINKY_CONFIG_INDEX] = {.gpio_pin = PINKY_SERVO_GPIO,
                            .ledc_channel = LEDC_CHANNEL_4,
                            .max_angle = 90,
                            .min_angle = 0,
                            .min_pulse_us = 700,
                            .max_pulse_us = 1600,
                            .max_speed = {120},
                            .direction = SERVO_DIR_REVERSE,
                            .name = "Pinky"},
    [WRIST_CONFIG_INDEX] = {.gpio_pin = TWIST_SERVO_GPIO,
                            .ledc_channel = LEDC_CHANNEL_5,
                            .min_angle = 0,
                            .max_angle = 140,
                            .min_pulse_us = 500,
                            .max_pulse_us = 2500,
                            .max_speed = {100},
                            .direction = SERVO_DIR_REVERSE,
                            .name = "Wrist"},
};

[[maybe_unused]]
static void reenable_can_task([[maybe_unused]] void* pvParameter) {
  while (true) {
    can_automatically_reenable_on_bus_off();
    vTaskDelay(pdMS_TO_TICKS(10));
  }
}

[[maybe_unused]]
static void imu_task([[maybe_unused]] void* pvParameter) {
  uint32_t can_error_count = 0;
  esp_err_t err = ESP_OK;
  uint32_t can_error_count_since_last_log = 0;

  const uint16_t period_ms = 10;
  TickType_t current_tick = xTaskGetTickCount();
  while (true) {
    xTaskDelayUntil(&current_tick, pdMS_TO_TICKS(period_ms));
    ImuRawData raw_data = {0};
    err = imu_read_data(&raw_data);
    if (err != ESP_OK) {
      ESP_LOGW(TAG, "Error reading IMU data: %s", esp_err_to_name(err));
      continue;
    }

    ImuData data = imu_to_mg_and_mdps(raw_data);

    ESP_LOGI(
        TAG,
        "Read IMU accel [%.2f, %.2f, %.2f] mG, gyro [%.2f, %.2f, %.2f] mdps",
        data.accel.x, data.accel.y, data.accel.z, data.gyro.pitch,
        data.gyro.roll, data.gyro.yaw);

    // We first copy the floats we want to send to a buffer so we can reverse
    // the bytes if necessary to guarantee that we send them in little-endian
    // byte order.
    float can_buf[1] = {0};

    can_buf[0] = htolef(data.gyro.pitch);
    err = can_send(CAN_ID_ROBOT_LOWER_ARM_IMU_GYRO_PITCH,
                   (const uint8_t*)can_buf, sizeof(can_buf), 0);
    if (err != ESP_OK) {
      ++can_error_count_since_last_log;
    }

    can_buf[0] = htolef(data.gyro.roll);
    err = can_send(CAN_ID_ROBOT_LOWER_ARM_IMU_GYRO_ROLL,
                   (const uint8_t*)can_buf, sizeof(can_buf), 0);
    if (err != ESP_OK) {
      ++can_error_count_since_last_log;
    }

    can_buf[0] = htolef(data.gyro.yaw);
    err = can_send(CAN_ID_ROBOT_LOWER_ARM_IMU_GYRO_YAW, (const uint8_t*)can_buf,
                   sizeof(can_buf), 0);
    if (err != ESP_OK) {
      ++can_error_count_since_last_log;
    }

    can_buf[0] = htolef(data.accel.x);
    err = can_send(CAN_ID_ROBOT_LOWER_ARM_IMU_ACCEL_X, (const uint8_t*)can_buf,
                   sizeof(can_buf), 0);
    if (err != ESP_OK) {
      ++can_error_count_since_last_log;
    }

    can_buf[0] = htolef(data.accel.y);
    err = can_send(CAN_ID_ROBOT_LOWER_ARM_IMU_ACCEL_Y, (const uint8_t*)can_buf,
                   sizeof(can_buf), 0);
    if (err != ESP_OK) {
      ++can_error_count_since_last_log;
    }

    can_buf[0] = htolef(data.accel.z);
    err = can_send(CAN_ID_ROBOT_LOWER_ARM_IMU_ACCEL_Z, (const uint8_t*)can_buf,
                   sizeof(can_buf), 0);
    if (err != ESP_OK) {
      ++can_error_count_since_last_log;
    }

    enum {
      kMinCanErrorCountPerLogging = 100,
    };
    if (can_error_count_since_last_log > kMinCanErrorCountPerLogging) {
      can_error_count += can_error_count_since_last_log;
      can_error_count_since_last_log = 0;
      ESP_LOGW(TAG, "CAN errors: %d, last_error: %s", can_error_count,
               esp_err_to_name(err));
    }
  }
}

static void can_rx_task([[maybe_unused]] void* pvParameter) {
  ESP_LOGI(TAG, "Starting CAN rx task");

  while (true) {
    uint32_t rx_id = 0;
    uint8_t rx_data[CAN_MAX_MESSAGE_SIZE] = {0};
    uint8_t rx_len = 0;

    esp_err_t err = can_receive(&rx_id, rx_data, &rx_len, portMAX_DELAY);
    if (err != ESP_OK) {
      ESP_LOGW(TAG, "Error receiving CAN message: %s", esp_err_to_name(err));
      continue;
    }

    if (rx_id == CAN_ID_ROBOT_THUMB_ACTUATION) {
      if (rx_len != 2 * sizeof(float)) {
        ESP_LOGW(TAG, "Received thumb activation with invalid len: %u", rx_len);
        continue;
      }

      float angle = deserialize_float(rx_data, kFromLittleEndian);
      AngularVelocity velocity = {
          deserialize_float(rx_data + sizeof(float), kFromLittleEndian)};
      servo_move_to_angle_with_speed(&s_servo_configs[THUMB_CONFIG_INDEX],
                                     angle, velocity);
      ESP_LOGI(TAG, "Actuation thumb to %.2f degrees at %.2f dps", angle,
               velocity.dps);
    } else if (rx_id == CAN_ID_ROBOT_INDEX_ACTUATION) {
      if (rx_len != 2 * sizeof(float)) {
        ESP_LOGW(TAG, "Received index activation with invalid len: %u", rx_len);
        continue;
      }

      float angle = deserialize_float(rx_data, kFromLittleEndian);
      AngularVelocity velocity = {
          deserialize_float(rx_data + sizeof(float), kFromLittleEndian)};
      servo_move_to_angle_with_speed(&s_servo_configs[INDEX_CONFIG_INDEX],
                                     angle, velocity);
      ESP_LOGI(TAG, "Actuation index to %.2f degrees at %.2f dps", angle,
               velocity.dps);
    } else if (rx_id == CAN_ID_ROBOT_MIDDLE_ACTUATION) {
      if (rx_len != 2 * sizeof(float)) {
        ESP_LOGW(TAG, "Received middle activation with invalid len: %u",
                 rx_len);
        continue;
      }

      float angle = deserialize_float(rx_data, kFromLittleEndian);
      AngularVelocity velocity = {
          deserialize_float(rx_data + sizeof(float), kFromLittleEndian)};
      servo_move_to_angle_with_speed(&s_servo_configs[MIDDLE_CONFIG_INDEX],
                                     angle, velocity);
      ESP_LOGI(TAG, "Actuation middle to %.2f degrees at %.2f dps", angle,
               velocity.dps);
    } else if (rx_id == CAN_ID_ROBOT_RING_ACTUATION) {
      if (rx_len != 2 * sizeof(float)) {
        ESP_LOGW(TAG, "Received ring activation with invalid len: %u", rx_len);
        continue;
      }

      float angle = deserialize_float(rx_data, kFromLittleEndian);
      AngularVelocity velocity = {
          deserialize_float(rx_data + sizeof(float), kFromLittleEndian)};
      servo_move_to_angle_with_speed(&s_servo_configs[RING_CONFIG_INDEX], angle,
                                     velocity);
      ESP_LOGI(TAG, "Actuation ring to %.2f degrees at %.2f dps", angle,
               velocity.dps);
    } else if (rx_id == CAN_ID_ROBOT_PINKY_ACTUATION) {
      if (rx_len != 2 * sizeof(float)) {
        ESP_LOGW(TAG, "Received pinky activation with invalid len: %u", rx_len);
        continue;
      }

      float angle = deserialize_float(rx_data, kFromLittleEndian);
      AngularVelocity velocity = {
          deserialize_float(rx_data + sizeof(float), kFromLittleEndian)};
      servo_move_to_angle_with_speed(&s_servo_configs[PINKY_CONFIG_INDEX],
                                     angle, velocity);
      ESP_LOGI(TAG, "Actuation pinky to %.2f degrees at %.2f dps", angle,
               velocity.dps);
    } else if (rx_id == CAN_ID_ROBOT_LOWER_ARM_ROTATION_ACTUATION) {
      if (rx_len != 2 * sizeof(float)) {
        ESP_LOGW(TAG, "Received rotation activation with invalid len: %u",
                 rx_len);
        continue;
      }

      float angle = deserialize_float(rx_data, kFromLittleEndian);
      AngularVelocity velocity = {
          deserialize_float(rx_data + sizeof(float), kFromLittleEndian)};
      servo_move_to_angle_with_speed(&s_servo_configs[WRIST_CONFIG_INDEX],
                                     angle, velocity);
      ESP_LOGI(TAG, "Actuation wrist to %.2f degrees at %.2f dps", angle,
               velocity.dps);
    }
  }
}

void app_main() {
  ESP_LOGI(TAG, "Starting servo control application");
  // vTaskDelay(pdMS_TO_TICKS(2000));

  // Initialize all servos
  ESP_LOGI(TAG, "Initializing servos...");
  servo_led_init(s_servo_configs, LIMB_ARR_LEN(s_servo_configs));
  // vTaskDelay(pdMS_TO_TICKS(1000));

#if CONFIG_IMU_ENABLED
  {
    ESP_LOGI(TAG, "Initializing IMUs...");
    ImuConfig imu_config = IMU_CONFIG_DEFAULT();
    imu_config.sda_pin = IMU_SDA_GPIO;
    imu_config.scl_pin = IMU_SCL_GPIO;
    ESP_ERROR_CHECK_WITHOUT_ABORT(imu_init(&imu_config));
    if (!imu_is_present()) {
      ESP_LOGW(TAG, "IMU isn't present");
      abort();
    }
  }
#endif

  // Initialize rotary encoder
  // ESP_LOGI(TAG, "Initializing rotary encoder...");
  // rotary_encoder_init();
  // vTaskDelay(pdMS_TO_TICKS(1000));

  // Start calibration mode
  // Uncomment the line below to enter calibration mode
  // start_calibration_mode();

  // init CAN CX---------------
  {
    esp_err_t err = can_init(CAN_TX_PIN, CAN_RX_PIN, CAN_BAUDRATE, NULL);
    if (err) {
      ESP_LOGE(TAG, "Couldn't start can driver: %s", esp_err_to_name(err));
      abort();
    }
  }

#if CONFIG_IMU_ENABLED
  {
    BaseType_t err =
        xTaskCreate(imu_task, "imu_task", 1024 * 2 * 2, NULL, 5, NULL);
    if (err != pdPASS) {
      ESP_LOGE(TAG, "Failed to create imu task, err code: %d", err);
      can_deinit();
      imu_deinit();
      abort();
    }
  }
#endif

#if CONFIG_FORCE_REENABLE_CAN_ON_BUS_OFF
  {
    BaseType_t err = xTaskCreate(reenable_can_task, "reenable_can_task",
                                 1024 * 2 * 2, NULL, 6, NULL);
    if (err != pdPASS) {
      ESP_LOGE(TAG, "Failed to create reenable_can_task, err code: %d");
      abort();
    }
  }
#endif

  {
    BaseType_t err =
        xTaskCreate(can_rx_task, "can_rx_task", 1024 * 2 * 2, NULL, 6, NULL);
    if (err != pdPASS) {
      ESP_LOGE(TAG, "Failed to create imu task, err code: %d", err);
      abort();
    }
  }
}

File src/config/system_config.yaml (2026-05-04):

# LIMB-HT25 System Configuration File
# This file configures all layers and hardware interfaces for the robotic control system

# Hardware interfaces configuration
hardware:
  can:
    interface: "can0"
    bitrate: 1000000 # bps
  ble:
    device_name: "LIMBServer"
    scan_timeout: 10.0 # seconds

# Input layer configuration
input_layer:
  window_size_ms: 200.0 # Window duration in milliseconds (matches hardware: 200ms)
  overlap_ms: 100.0 # Overlap between windows in milliseconds (50% overlap: 200ms window, 100ms overlap)
  emg_frequency: 4000.0 # EMG sampling frequency in Hz
  imu_frequency: 100.0 # IMU sampling frequency in Hz
  piezo_frequency: 100.0 # Piezo sampling frequency in Hz

  potentiometer_mapping:
    shoulder_up_down: 0
    shoulder_left_right: 1
    elbow_up_down: 2
    upper_arm_rotation: 3

# Processing layer configuration
processing_layer:
  # ML model paths
  model:
    path: null # Path to LSTM model checkpoint (.pth file)
    scaler_path: null # Path to StandardScaler pickle file
    config:
      input_dim: 6 # Input dimension for LSTM
      hidden_dim: 32 # Hidden dimension for LSTM

  # EMG signal processing
  emg:
    fs: 1000.0 # Sampling frequency in Hz
    lowcut: 20.0 # Lower cutoff frequency in Hz
    highcut: 450.0 # Upper cutoff frequency in Hz
    notch_freq: 50.0 # Notch frequency in Hz (for power line noise)

  # Feature extraction parameters
  features:
    window_size_ms: 200.0 # Window size in milliseconds
    overlap_ms: 100.0 # Overlap in milliseconds

  # LSTM sequence parameters
  lstm:
    seq_length: 10 # Number of windows in the sequence
    num_classes: 2 # Number of classes for classification

  # IMU movement intention detection
  imu_intention:
    accel_threshold: 0.3 # Minimum acceleration to detect movement (m/s²)
    gravity_removal: true # Remove gravity from acceleration
    velocity_threshold: 0.2 # Velocity threshold in m/s
    direction_timeout: 4.0 # Timeout before allowing new direction detection (seconds)
    # Stillness detection thresholds
    accel_still_thresh: 0.5 # m/s²
    gyro_still_thresh: 0.1 # rad/s
    deadband_thresh: 0.15 # m/s²
    velocity_decay: 0.95 # Decay factor per sample
    gravity_ema_alpha: 0.05 # EMA smoothing for gravity vector
    madgwick_beta: 0.05 # Madgwick filter gain
    bias_update_duration: 0.5 # seconds

  # IMU+Vision fusion parameters
  fusion:
    # Complementary filter
    complementary_filter:
      alpha: 0.98 # Trust factor for orientation fusion
      alpha_position: 0.95 # Trust factor for position fusion

    # Extended Kalman Filter
    ekf:
      process_noise:
        pos: 1.0 # Position process noise (mm²)
        vel: 10.0 # Velocity process noise (mm²/s²)
        orient: 0.01 # Orientation process noise (rad²)
        angvel: 0.1 # Angular velocity process noise (rad²/s²)
      measurement_noise:
        vision_pos: 25.0 # Vision position measurement noise (mm²)
        vision_orient: 0.01 # Vision orientation measurement noise (rad²)
        imu_orient: 0.005 # IMU orientation measurement noise (rad²)

# Control layer configuration
control_layer:
  control_rate: 100.0 # Control loop frequency in Hz
  conf_threshold: 0.5 # LSTM confidence threshold for grip intention

  # State machine thresholds
  thresholds:
    hand_cup_distance: 0.2 # Maximum distance for hand-cup approach (meters)
    placement_distance: 0.1 # Maximum distance for valid placement (meters)

  # Motor primitives
  motor_primitives:
    step_size: 0.05 # Step size per movement command (meters)
    default_joint_velocity_dps: 10.0

  # Workspace limits (in meters)
  workspace_limits:
    x: [-0.5, 0.5] # X-axis limits
    y: [-0.5, 0.5] # Y-axis limits
    z: [0.0, 0.8] # Z-axis limits (height)

  # Joint limits (in radians)
  ###  joint_limits:
  #- [-3.14, 3.14]  # Joint 1: ±180 degrees
  #- [-1.57, 1.57]  # Joint 2: ±90 degrees
  #- [-3.14, 3.14]  # Joint 3: ±180 degrees
  #- [-1.57, 1.57]  # Joint 4: ±90 degrees
  #- [-3.14, 3.14]  # Joint 5: ±180 degrees

  joint_limits:
    - [0.0, 0.52] # Joint 1: Shoulder Up/Down (0 à 30 degrés)
    - [0.0, 0.70] # Joint 2: Shoulder Left/Right (0 à 40 degrés)
    - [0.0, 1.17] # Joint 3: Elbow (0 à 67 degrés)
    - [0.0, 1.57] # Joint 4: Upper Arm Rotation (0 à 90 degrés)
    - [-1.57, 1.57] # Joint 5: Lower Arm Rotation (±90 degrés)
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

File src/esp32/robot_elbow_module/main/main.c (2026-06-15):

#include "adc_manager.h"
#include "can_driver.h"
#include "esp_err.h"
#include "esp_log.h"
#include "freertos/FreeRTOS.h"
#include "freertos/projdefs.h"
#include "freertos/task.h"
#include "hal/adc_types.h"
#include "hal/ledc_types.h"
#include "imu.h"
#include "limb_utils.h"
#include "portmacro.h"
#include "potentiometer.h"
#include "soc/gpio_num.h"
#include "stepper.h"

static const char* const TAG = "robot_elbow_module";

enum {
  // CAN configuration
  CAN_TX_PIN = GPIO_NUM_0,
  CAN_RX_PIN = GPIO_NUM_1,
  CAN_BAUDRATE = 1000000,

  // IMU pins.
  IMU_SDA_PIN = GPIO_NUM_3,
  IMU_SCL_PIN = GPIO_NUM_4,

  // GPIO pin definitions
  // The enable pin is enabled by default.
  STEPPER_ELBOW_ENABLE_PIN = GPIO_NUM_NC,
  STEPPER_ELBOW_DIR_PIN = GPIO_NUM_6,
  STEPPER_ELBOW_STEP_PIN = GPIO_NUM_7,

  // ADC channels
  ADC_ELBOW_CHANNEL = ADC_CHANNEL_2,  // GPIO 2

  // PWM timers and channels
  PWM_ELBOW_CHANNEL = LEDC_CHANNEL_0,
  PWM_ELBOW_TIMER = LEDC_TIMER_0,
};

// Stepper configurations
static const stepper_control_config_t s_elbow_stepper_cfg = {
    .step_gpio = STEPPER_ELBOW_STEP_PIN,
    .dir_gpio = STEPPER_ELBOW_DIR_PIN,
    .enable_gpio = STEPPER_ELBOW_ENABLE_PIN,

    // Set these if you want microstepping.
    .microstepping_type = MICROSTEP_HARDWARE,
    .microstepping_mode = MICROSTEP_1_32,
    // We're setting the stepper driver's pins in hardware, so we don't need to
    // use them in the software.
    .microstep_m0_gpio = GPIO_NUM_NC,
    .microstep_m1_gpio = GPIO_NUM_NC,
    .microstep_m2_gpio = GPIO_NUM_NC,

    .direction = STEPPER_DIR_REVERSE,
    .steps_per_rev = 200,
    .gear_ratio = 15.0F,
    .max_speed_decreasing_angle = {40.0F},
    .max_speed_increasing_angle = {40.0F},
    .max_accel = {20.0F},
    .pwm_channel = PWM_ELBOW_CHANNEL,
    .pwm_timer = PWM_ELBOW_TIMER,
    .potentiometer =
        (Potentiometer){
            .range_of_motion = {285.F},
            // We step down voltage we feed to the potentiometer from 3300 mV to
            // 2200 mV.
            .min_adc_value = 0,
            .max_adc_value = 2200,
            .min_potentiometer_angle_as_joint_angle = {0.F},
            // Angle increases as the elbow is pulled in.
            .min_potentiometer_angle = {123.F},
            // Using the ratio between the joint angles and potentiomter angles,
            // 72 degrees of potentiometer angle becomes 60 degrees
            // of joint angle.
            .max_potentiometer_angle = {195.F},
            .joint_angle_to_potentiometer_angle_ratio = 18.F / 15.F,
            .is_reversed = true,
        },
};

// ADC manager configuration.
static const AdcMgrChannelConfig s_adc_mgr_channel_configs[] = {
    {
        .channel = ADC_ELBOW_CHANNEL,
        .sample_rate = 1000,
    },
};

static const AdcMgrConfig s_adc_mgr_config = {
    .channel_configs = s_adc_mgr_channel_configs,
    .channel_configs_len = LIMB_ARR_LEN(s_adc_mgr_channel_configs),
    .ms_worth_of_buffer_size = 100,
};

// NOLINTBEGIN(cppcoreguidelines-avoid-non-const-global-variables)
// Assuming a sample rate of 1 kHz, we can comfortably keep a buffer of 1
// seconds worth of data.
enum {
  ADC_STEPPERS_UNDERLYING_BUF_SIZE = 1000,
};

static uint16_t
    s_adc_elbow_channel_underlying_buffer[ADC_STEPPERS_UNDERLYING_BUF_SIZE] = {
        0};

static AdcMgrReadResults s_adc_mgr_read_results = {
    .channel_buffers = {
        [ADC_ELBOW_CHANNEL] = {.data = s_adc_elbow_channel_underlying_buffer,
                               .capacity = LIMB_ARR_LEN(
                                   s_adc_elbow_channel_underlying_buffer)},
    }};

static AdcMgrChannelBuffer* s_adc_mgr_elbow_buffer =
    &s_adc_mgr_read_results.channel_buffers[ADC_ELBOW_CHANNEL];

static uint16_t s_latest_potentiometer_adc_value;

static stepper_control_handle_t s_elbow_stepper_handle = {0};
// NOLINTEND(cppcoreguidelines-avoid-non-const-global-variables)

static void can_rx_task([[maybe_unused]] void* pvParameter) {
  uint8_t msg_rx[CAN_MAX_MESSAGE_SIZE];
  uint8_t rx_len = CAN_MAX_MESSAGE_SIZE;
  uint32_t rx_id = 0;

  while (1) {
    esp_err_t err = can_receive(&rx_id, msg_rx, &rx_len, portMAX_DELAY);
    if (err != ESP_OK) {
      ESP_LOGW(TAG, "Error calling can_receive: %s", esp_err_to_name(err));
      continue;
    }

    switch (rx_id) {
      case CAN_ID_ROBOT_ELBOW_UP_DOWN_ACTUATION: {
        enum {
          kExpectedPayloadSize = 2 * sizeof(float),
        };
        if (rx_len != kExpectedPayloadSize) {
          ESP_LOGW(
              TAG,
              "Invalid actuation payload length for elbow: %u (expected %u)",
              rx_len, kExpectedPayloadSize);
          break;
        }

        JointAngle target_angle = {
            deserialize_float(msg_rx, kFromLittleEndian)};
        AngularVelocity target_velocity = {
            deserialize_float(msg_rx + sizeof(float), kFromLittleEndian)};
        stepper_set_target_angle(s_elbow_stepper_handle, target_angle);
        stepper_set_target_velocity(s_elbow_stepper_handle, target_velocity);
        ESP_LOGI(TAG,
                 "Received elbow actuation: angle=%f degrees, velocity=%f dps",
                 target_angle.degree, target_velocity.dps);
        break;
      }
      case CAN_ID_ROBOT_ELBOW_UP_DOWN_STOP: {
        stepper_set_estop(s_elbow_stepper_handle, true);
        ESP_LOGI(TAG, "Received stop command: 0x%x", rx_id);
        break;
      }
      default: {
        ESP_LOGW(TAG, "Received unknown CAN message: 0x%x", rx_id);
      }
    }
  }
}
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

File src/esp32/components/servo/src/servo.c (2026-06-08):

#include "servo.h"

#include <math.h>

#include "driver/ledc.h"
#include "esp_err.h"
#include "hal/ledc_types.h"
#include "limb_utils.h"

static const char* const TAG = "Servo";

// We support a static amount of servo motors, so we statically allocate space
// for them.
// NOLINTBEGIN(cppcoreguidelines-avoid-non-const-global-variables)
static servo_config_t s_servo_configs[LEDC_CHANNEL_MAX] = {0};
// NOLINTEND(cppcoreguidelines-avoid-non-const-global-variables)

// Convert microseconds to duty cycle
uint32_t us_to_duty(uint32_t us) {
  us = LIMB_CLAMP(us, SERVO_MIN_US, SERVO_MAX_US);
  return (uint32_t)((uint64_t)SERVO_MAX_DUTY * us / SERVO_PERIOD_US);
}

uint32_t duty_to_us(uint32_t duty) {
  return (uint32_t)((uint64_t)duty * SERVO_PERIOD_US / SERVO_MAX_DUTY);
}

float pulse_width_to_angle(const servo_config_t* servo, uint16_t pw_us) {
  float angle = LIMB_LERP_FROM_RANGE((float)pw_us, (float)servo->min_pulse_us,
                                     (float)servo->max_pulse_us,
                                     servo->min_angle, servo->max_angle);
  if (servo->direction == SERVO_DIR_REVERSE) {
    angle = servo->min_angle + (servo->max_angle - angle);
  }
  return angle;
}

uint16_t angle_to_pulse_width(const servo_config_t* servo, float angle_deg) {
  angle_deg = LIMB_CLAMP(angle_deg, servo->min_angle, servo->max_angle);
  if (servo->direction == SERVO_DIR_REVERSE) {
    angle_deg = servo->min_angle + (servo->max_angle - angle_deg);
  }
  const float us =
      LIMB_LERP_FROM_RANGE(angle_deg, servo->min_angle, servo->max_angle,
                           servo->min_pulse_us, servo->max_pulse_us);
  return (uint16_t)us;
}

// Initialize all servos
esp_err_t servo_led_init(const servo_config_t* servos, size_t servos_size) {
  if (servos_size > LIMB_ARR_LEN(s_servo_configs)) {
    ESP_LOGE(TAG, "Tried to initialize more servos than are supported (%u)",
             LIMB_ARR_LEN(s_servo_configs));
    return ESP_ERR_INVALID_ARG;
  }

  ESP_LOGI(TAG, "Initializing LEDC for %d servos", servos_size);

  // Configure LEDC timer (shared by all servos)
  ledc_timer_config_t ledc_timer = {.speed_mode = LEDC_LOW_SPEED_MODE,
                                    .duty_resolution = SERVO_RES_BITS,
                                    .timer_num = LEDC_TIMER_0,
                                    .freq_hz = SERVO_FREQ_HZ,
                                    .clk_cfg = LEDC_AUTO_CLK};
  ESP_ERROR_CHECK(ledc_timer_config(&ledc_timer));

  ESP_LOGI(TAG, "Timer configured");
  // Configure each servo channel individually
  for (int i = 0; i < servos_size; i++) {
    ESP_LOGI(TAG, "Configuring %s on GPIO%d, Channel %d", servos[i].name,
             servos[i].gpio_pin, servos[i].ledc_channel);

    ledc_channel_config_t channel_config1 = {.gpio_num = servos[i].gpio_pin,
                                             .speed_mode = LEDC_LOW_SPEED_MODE,
                                             .channel = servos[i].ledc_channel,
                                             .intr_type = LEDC_INTR_DISABLE,
                                             .timer_sel = LEDC_TIMER_0,
                                             .duty = 0,
                                             .hpoint = 0};

    ESP_ERROR_CHECK(ledc_channel_config(&channel_config1));
    vTaskDelay(pdMS_TO_TICKS(10));
  }

  ledc_fade_func_install(0);

  ESP_LOGI(TAG, "All channels configured, setting initial positions");

  // Initialize all servos to their center position.
  for (int i = 0; i < servos_size; i++) {
    const servo_config_t* servo = &servos[i];
    const float mid_angle =
        servo->min_angle + ((servo->max_angle - servo->min_angle) / 2.F);
    servo_move_to_angle(servo, mid_angle);  // Start at center position
    vTaskDelay(pdMS_TO_TICKS(50));  // Small delay between servo movements
  }

  // Copy the configs.
  for (int i = 0; i < servos_size; i++) {
    s_servo_configs[i] = servos[i];
  }

  ESP_LOGI(TAG, "All servos initialized at neutral position");
  // vTaskDelay(pdMS_TO_TICKS(2000));
  return ESP_OK;
}

void servo_move_to_angle_with_speed(const servo_config_t* servo, float angle,
                                    AngularVelocity speed) {
  const AngularVelocity clamped_speed = {MIN(speed.dps, servo->max_speed.dps)};
  const float clamped_angle =
      LIMB_CLAMP(angle, servo->min_angle, servo->max_angle);

  // We find the current angle based on the current duty.
  const uint32_t current_duty =
      ledc_get_duty(LEDC_LOW_SPEED_MODE, servo->ledc_channel);
  const uint16_t current_us = duty_to_us(current_duty);
  const float current_angle = pulse_width_to_angle(servo, current_us);

  const float abs_angle_diff = fabsf(clamped_angle - current_angle);
  // Don't move if we're close to the angle.
  const float deadband = 0.5F;
  if (abs_angle_diff < deadband) {
    return;
  }
  const uint16_t time_to_move_ms =
      (uint16_t)(abs_angle_diff / clamped_speed.dps * 1000.F);

  const ledc_channel_t channel = servo->ledc_channel;

  const uint16_t us = angle_to_pulse_width(servo, clamped_angle);
  const uint32_t duty = us_to_duty(us);

  // Since we're starting a new fade, we stop the previous fade in case it's
  // not done yet.
  ESP_ERROR_CHECK_WITHOUT_ABORT(ledc_fade_stop(LEDC_LOW_SPEED_MODE, channel));
  ESP_ERROR_CHECK_WITHOUT_ABORT(ledc_set_fade_time_and_start(
      LEDC_LOW_SPEED_MODE, channel, duty, time_to_move_ms, LEDC_FADE_NO_WAIT));
  ESP_LOGI(TAG, "%s -> %f° (%u us)", servo->name, angle, us);
}

void servo_fade_to_angle(const servo_config_t* servo, float angle,
                         uint32_t fade_ms) {
  const uint16_t us = angle_to_pulse_width(servo, angle);
  const uint32_t duty = us_to_duty(us);

  ESP_ERROR_CHECK_WITHOUT_ABORT(
      ledc_fade_stop(LEDC_LOW_SPEED_MODE, servo->ledc_channel));
  ESP_ERROR_CHECK_WITHOUT_ABORT(
      ledc_set_fade_time_and_start(LEDC_LOW_SPEED_MODE, servo->ledc_channel,
                                   duty, fade_ms, LEDC_FADE_NO_WAIT));

  ESP_LOGI(TAG, "%s -> %f° (%u us)", servo->name, angle, us);
}

// Write angle to specific servo channel
void servo_move_to_angle(const servo_config_t* servo, float angle) {
  const uint16_t us = angle_to_pulse_width(servo, angle);

  // Set duty cycle
  const uint32_t duty = us_to_duty(us);
  ledc_set_duty(LEDC_LOW_SPEED_MODE, servo->ledc_channel, duty);
  ledc_update_duty(LEDC_LOW_SPEED_MODE, servo->ledc_channel);

  ESP_LOGI(TAG, "%s -> %f° (%u us)", servo->name, angle, us);
}

// ============================================================================
// GESTURE IMPLEMENTATION
// ============================================================================
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

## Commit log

2025-09-17 Enabled two modes: cup and tag detection. Added ArUco tag and ChArUco board generation. Added camera calibration.
2025-09-17 Added YOLO models for cup detection. Removed cup detection solution without YOLO. Changed names of files and classes to more generalized formats. Fixed bug where camera window did not show when runni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
    Remove to large YOLO model files (medium, large and extra large)
    Added YOLO models for cup detection (small and nano). Removed cup detection solution without YOLO. Changed names of files and classes to more generalized formats. Fixed bug where camera window did not show when running the tag detection
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2025-09-19 Simplified the system so that it only contains cup and tag detection as a start. Fixed 'bug' where the detection was ran twice and causing latency problems. Put the test codes in a separate folder. S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
2025-09-22 KiCad-design. EMG with RLD
    [EMG-KiCad.kicad_pcb, EMG-KiCad.kicad_sch]
2025-09-24 Started building a setup for the IMU reading that will be combined with the vision system for pose estimation at later stages
2025-09-24 Added alignment between the tags and visualize real-world coordinates with relation to the camera as the origin
2025-09-24 Added a combined mode with both cup and tag. In that mode, I added a line between the center of the cup and predefined tag if they are in the same frame and display the distance between them
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2025-09-29 Optimized the vision system with threading, optimized camera capture and better yolo inference. Added a benchmark system for performance monitoring. Added a test script.
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2025-09-30 Added IMU and Vision fusion. Made small changes to pathing of vision files.
2025-09-30 Complete schematic and add custom library
    [EMG-KiCad.kicad_sch]
2025-09-30 add libraries and change schematic
    [EMG-KiCad.kicad_pcb, EMG-KiCad.kicad_sch]
2025-10-01 Changed visual outlooks and added states for the arm that can be visualized.
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2025-10-02 complete the pcb traces
    [EMG-KiCad.kicad_pcb, EMG-KiCad.kicad_sch]
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2025-10-03 Made the necessary change to adapt for the tag detection results in the imu and vision fusion system. Also modified the README in the imuvision folder as well as in the vision folder
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2025-10-07 Added code so that data is sent in json format to serial reader in Python. The IMU data is read and combined with the vision system
2025-10-07 Did som major restructuring of the src code. Better modularity, adhere to the discretized movement of the arm.
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2025-10-13 First Prototype - Forearm
    [Pocket-EMGpcb.STL, forearm-big.STL]
2025-10-13 Change the state machine to adapt to the new structure of intention classification only with EMG and direction information from IMU
2025-10-15 Updated files
    [EMG-Routing_2 - Board Outline.gbr, EMG-Routing_2 - Copper Bottom.gbr, EMG-Routing_2 - Copper Top-Copper Bottom.drl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]
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2025-10-16 Cuff for Piezo
    [forearm-small.STL]
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2025-10-20 ADCEMG and IMU projects are build as separate modules. Creating simple setup for Human Arm with both EMG and IMU modules
2025-10-21 New version of the vision system based on OAK D camera. Implemented with DepthAI library. Includes cup detection, depth measurement, april tag detection, extrinsic calibration. Additional, simple tes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
2025-10-23 Updated the data fusion system with IMU and vision using the DepthAI library. It implements three demos: IMU-only tracking, IMU-vision tracking with a complementary filter and with an EKF filter. Int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
2025-10-23 Added script for returning intrinsic camera calibration data, optionally user or factory data
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2025-10-27 integration of ADC and IMU capturing with Johan's BLE TX, sending one sample of a window. Adding a IA generated script in Python for capturing the data via BLE
2025-10-31 Fix *_buf_size_in_ms calculation
    The change to k*BytesPerSample to not take the sensor count into account
    broke the *_buf_size_in_ms calculation.
2025-10-31 Update sensor settings to avoid packet loss
    The ESP32-C3 had a bunch of packet loss due to running out of memory
    when calling `ble_gatts_notify`. We should be able to get by with lower
    sampling rates for the sensors, so we can reduce the amount of data sent
    that way.
    [sensors_service.h]
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2025-10-31 Add a deserialize_packet_data function
    This function can be used for deserializing the packet data for all the
    different sensors, assuming that they follow the same format of:
    [
    sensor1sample1value1, sensor1sample1value2,
    sensor2sample1value1, sensor2sample1value2,
    sensor1sample2value1, sensor1sample2value2,
    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
2025-10-31 Add a SampleWindow class
    The class holds a sliding window of samples that obey the communication
    characteristics of some sensor.
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2025-11-06 Added a template schema for EMG collection. Generated by ChatGPT, not fully adapted to this specific case
2025-11-06 Organize the repository
    [EMG-KiCad.kicad_pcb, EMG-KiCad.kicad_sch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]
2025-11-11 The working version of the CAN transceiver design.
    [CAN_Transceiver.kicad_pcb, CAN_Transceiver.kicad_sch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]
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2025-11-18 Update servo angle limits for thumb, index, and middle fingers; remove unused functions
2025-11-19 Removed left over that was supposed to be deleted, small bug fix
    [imu.h]
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2025-11-20 Changes the potentiometer component so that it uses the ADC manager. Fixed ADC unit 1 for the potentiometer
2025-11-20 Tested the potentiometer (based on the adc manager) with experimental simple script. Works.
2025-11-20 Added short README files for adc manager, imu and potentiometer
2025-11-20 Make struct default macros use compound literals
    Using compound literals allows the macro to also be used with
    assignments instead of just initializations.
    ```c
    typedef struct {
    int a;
    } A;
    // Regular literals.
    A a = {0}; // Works.
    a = a; // Doesn't work.
    // Compound literal.
    A a = (A) {0}; // Works.
    a = (A) {0}; // Also works.
    ```
    [imu.h]
2025-11-20 Refactor HS422 servo control: update pulse width settings, streamline functions, and enhance initialization process
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2025-11-24 Refactor servo control: update servo directions, add rock and flip off gestures, and streamline gesture execution in main loop
    [HS422_led.c, main.c]
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2025-11-26 Simulation implementation
    [bicep.stl, bicepcover.stl, index3_1.stl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]
2025-11-26 Fix broken code in can_driver example
    [main.c]
2025-11-26 Fix uninitialized variable in CAN driver
2025-11-28 Added two components: stepper and servo (ax12). Added test scripts (stepper and servo) to test the components. The stepper is not working as intended though.
    [main.c, stepper.c, stepper.h]
2025-11-28 Implemented a simple robot elbow (lower arm) program that reads (some) IMU data and actuate stepper + read from potentiometer. CAN is commented out and not tested with the implementation. Stepper dri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
2025-11-28 Tested robot elbow node with CAN between two ESP32s - worked fine. Made a script to send commands via CAN that after the testing was moved to experiments and thus might need some editing to use it ag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
2025-12-02 Changes to the previous AX12 servo control implementation. This one is a library found online.
2025-12-02 Remove the piezo component
    With the continuous version of the ADC manager, when a read operation is
    performed, the caller will receive all available values for all
    subscribed channels. In that scenario, having separate components that
    rely on the ADC doesn't make much sense unless processing functions are
    required.
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2025-12-02 Remove unnecessary inline specifier
    Inline doesn't actually deal with inlining nowadays.
    [stepper.c]
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2025-12-03 Fix attenuation for continuous ADC manager
    Using an attenuation of 0 dB, we can only measure input voltages up to
    around 950 mV. Using an attenuation of 12 dB instead allows us to
    measure up to around 2450 mV.
    [adc_manager.c]
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2025-12-04 Remove experiments that use missing components
    [main.c]
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2025-12-09 Update/fix the elbow_command_node experiment
    [main.c]
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2025-12-11 Fix floats being printed as ints
    [main.c]
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2025-12-20 Replace LIMB_MAX macro with MAX in <sys/param.h>
    [adc_manager.c]
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2025-12-30 elbow node: Return from app_main if initializations fail
    [main.c]
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2025-12-30 stepper: Don't set a frequency lower than 5 Hz
    The LEDC library errors when it's initialized with a frequency lower
    than 5 Hz. ledc_find_suitable_duty_resolution also returns 0 for any
    value below 5 Hz. At 5 Hz, it instead returns 14, and trying to set
    another duty resolution seems to also cause an error, so we'll go with
    14 bits instead of 13.
    [stepper.c]
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2025-12-30 stepper: Allow reversing direction in config
    [main.c, stepper.c, stepper.h]
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2025-12-30 stepper: Don't disable motor when stopping it
    Disabling the motor means it is no longer locked in place, so
    sufficient torque will turn it. Gravity acting on the arm caused enough
    torque to not keep it in place once the motor stopped.
    [stepper.c]
2025-12-30 elbow node: Replace local enum
    [main.c]
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2026-01-03 Fix piezo samples not being added to the window buffer
2026-01-03 Allow setting a ratio between `JointAngle`s and `PotentiometerAngle`s
    For some of the joints, the potentiometer doesn't rotate 1 to 1 with
    the joint. So we need to be able to convert between the potentiometer's
    angles and the corresponding joint angle.
    fixup
    [main.c, robot_shoulder_module.c]
2026-01-03 servo: Rework component for proper continuous movement
    The initial attempt at connecting our own potentiometer to the servo
    didn't work due to unstable voltages when the motor switched between
    running and being still. Our solution is to remove the servo's
    potentiometer entirely, making it so that the servo thinks its
    potentiometer is always at the midway point, which corresponds to a
    pulse width of 1500 us. By setting the pulse width to values above and
    below 1500 us, we end up being able to roughly control the angular
    velocity of the servo. This allows us to control its movement using the
    `servo_update` function.
    [servo.c, servo.h]
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2026-01-03 shoulder: Fix servo usage
    [imu.h, robot_shoulder_module.c]
2026-01-03 shoulder: Remove IMU code
    The shoulder node won't be connected to any IMU.
    [robot_shoulder_module.c]
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2026-01-03 elbow: Fix gear ratio and min/max ADC values
    [main.c]
2026-01-03 elbow: Set correct potentiometer values in configuration.
    [main.c]
2026-01-03 elbow: Terminate if anything fails during initialization
    [main.c]
2026-01-03 elbow: Make sure elbow test task doesn't switch target angle immediately
    [main.c]
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2026-01-03 elbow: Send angle over CAN every period
    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
    [main.c]
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2026-01-03 elbow: Prioritize tasks
    Moving the motor is the highest priority to make sure it doesn't extend
    past its limits. After that, receiving stop and actuation messages over
    CAN are important to make sure we quickly respond to commands.
    [main.c]
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2026-01-04 shoulder: Remove FIXME comments for left/right config
    [robot_shoulder_module.c]
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2026-01-04 servo: Actually reverse motor if set in config
    [servo.c]
2026-01-04 shoulder: Swap Vin and ground for up/down potentiometer
    The ADC is less accurate the closer the voltage is to 0, so by swapping
    the Vin and ground on the potentiometer, we hopefully get more accurate
    readings.
    [robot_shoulder_module.c]
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2026-01-05 servo: Fix target angle not being set in init function
    [servo.c]
2026-01-05 shoulder: Fix incorrect handle being used in can_rx_task
    [robot_shoulder_module.c]
2026-01-06 Fix CAN IDs in can_message_parser
    Some of the CAN messages got changed since one of the motors had to be
    moved to the shoulder node.
2026-01-06 Fix IMU directions based on its orientation in the cuff
    The IMU is angled such that the "forward" direction faces up and the
    "left" direction faces forward.
    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
2026-01-06 elbow: Use correct pins
    [main.c]
2026-01-06 potentiometer: Add ability to reverse joint relationship
    You might have a situation where the potentiometer has a range from 120
    to 150, where an increase in value moves a joint clockwise. However,
    from the user's perspective, it might make more sense for the increase
    in value to move the joint counterclockwise. So if the joint angles go
    from 0 to 30, the 0 would normally be associated with the potentiometer
    angle 120 and the 30 would be the potentiometer angle 150.
    This feature allows for the relationship to be reversed, so the joint
    angle 0 is associated with the potentiometer angle 150 and joint angle
    30 with potentiometer angle 120.
2026-01-07 elbow: Set correct config angle values
    [main.c]
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2026-01-07 Fix invalid handle and name in logging
    [robot_shoulder_module.c]
2026-01-07 Reduce frequency of CAN error logging
    If a CAN error ever occurs, it's probably going to keep occurring,
    leading to task watchdog being triggered due to excessive logging.
    [main.c, robot_shoulder_module.c]
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2026-03-30 Revert "IMU: Add ability to use multiple IMUs"
    This reverts commit 830ce5afcdf231bf2c67dd96277c1b9fc28e1762.
    [imu.c, imu.h]
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2026-04-08 Invert condition to allow for early continue
    [adc_service.c]
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2026-04-08 Replace stream_control_t with SampleBuffers
    stream_control_t acted like a length field on top of the data fields of
    s_emg_packet and s_piezo_packet, so we can create an actual buffer type
    that better conforms to the idea of what's happening.
    [adc_service.c]
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2026-04-08 Replace macros with constants in sensors_service.h
    [adc_service.c, imu_service.c]
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2026-04-08 Fix attempting to print EMG2 data
    [ble_service.c]
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2026-04-15 Fix passing wrong number of arguments to can_send
    [main.c]
2026-04-16 Error if CAN fails to init
    [main.c]
2026-04-16 Change CAN TX GPIO pin
    The GPIO 9 pin is a strapping pin, meaning that if bits are being
    transmitted over the CAN bus while rebooting the ESP32-C3-zero, the
    ESP might enter joint download boot mode instead of booting normally.
    [main.c]
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2026-04-16 Fix servo_get_current_angle returning target_angle
    [servo.c]
2026-04-16 Reverse up/down servo joint angles
    We want the up/down angle to be 0 when the arm is aimed straight down.
    Currently, the potentiometer angle increases as the arm moves down and
    decreases as the arm moves up. By setting `is_reversed`, we make sure
    that the joint angle reverses the relationship, so that the joint angle
    instead decreases as the arm moves down and increases as the arm moves
    up.
    [robot_shoulder_module.c]
2026-04-23 Shoulder: Modify upper arm rotation min angle
    The arm's rotation at 0 degrees didn't have the arm facing straight
    forward.
    [robot_shoulder_module.c]
2026-04-23 Fix: Combine separate period variable definitions
    [main.c]
2026-04-23 Servo: Use a frequency of 330 Hz instead of 50 Hz
    The HV2060 supports a frequency of 330 Hz, so setting it to 330 Hz
    we make sure we are able to update the pulse width as fast as possible.
    Since we update the velocity of the motors with a frequency of 100 Hz,
    having a frequency of 50 Hz also makes it so we end up skipping every
    other velocity motor update since we try to set the new pulse width in
    the middle of the previous one.
    [servo.c]
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2026-04-28 IMU: Enable Block Data Update (BDU)
    Enabling BDU makes sure that while the output registers are being read,
    they aren't updated with a new sample value until both the most
    significant and least significant bytes have been read, preventing a
    situation where the least significant byte is from sample N while the
    most significant byte is from sample N + 1.
    [imu.c]
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2026-05-04 Utils: Add float marshalling functionality
    When sending data over the wire, we want to send it in little-endian
    byte order. For integers this can be done with the htole** and le**toh
    macros, but there's no such macro for floats, so this commit adds that
    functionality. Additionally, a function is added to deserialize a float
    that has been received as a byte buffer. The deserialization is
    performed in a way that avoids strict aliasing issues.
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2026-05-07 CAN: Add separate IDs for each IMU sample value
    Since we want to switch to sending floats for the IMU sample values, we
    can no longer fit all accel or gyro values into single CAN messages.
    Instead we create separate IDs for each sample value, sending a single
    float with each message.
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2026-05-19 Human arm: Fix not printing entire IMU sample as floats
    [ble_service.c]
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2026-05-19 Call abort() instead of returning from the app_main
    Returning from app_main means the system stays in the state it's in at the
    point of the return, meaning that other tasks that have been created keep on
    running and pins that have been configured stay active unless deinitialized.
    Calling abort() instead induces a panic and reboots the system. This also helps
    with e.g. the IMU connection, which sometimes takes a couple of reboots to
    actually establish a proper connection.
    [main.c, robot_shoulder_module.c]
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2026-05-19 Hand motor: Fix IMU task period
    [main.c]
2026-05-19 Hand motor: Fix IMU logging not using floats
    [HS422_led.c, main.c]
2026-05-19 Hand motor: Set measured min and max angles and pulse widths
    The angles are eyeballed and the pulse width range seems like
    it can change depending on if the second finger joint gets stuck
    or not and if force is applied to a finger while it's being actuated.
    [HS422_led.c]
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2026-05-19 Add sdkconfig.defaults files for important settings
    We want the maximum tick rate possible, which for ESP32-C3-Zeros is 1000 Hz.
    For the MCs on the robot arm, they are powered by a power supply, so we don't
    have to worry about increased power consumption. For the MC on the human arm,
    it's powered by a battery, but since we send data over BLE at a high rate, we
    still need a high tick rate anyway.
    Having a panic reboot delay of 0 seconds results in a bunch of serial
    communication being queued up when monitoring the program, which prevents the
    monitoring from being canceled. Adding a 1 second delay makes it responsive
    again.
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2026-05-21 Added all the kicad files for the custom PCBs
    [Adafruit_ISM330DHXC.STEP, ESP32-C3_Zero.step, LIMB_Biceps.kicad_pcb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]
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2026-05-30 Stepper: Don't set target_velocity to 0 in stop_motor
    If the target_velocity gets set to 0 after the stepper reaches its
    destination, it won't be able to adjust if its position gets altered
    in some way.
    [stepper.c]
2026-05-30 Motors: Add safety measures for extreme potentiometer angles
    If the reading from a potentiometer is close to its limits, it might
    mean that the connection from the potentiometer to the ADC is bad or
    that the arm has for some reason moved too far. In these situations, we
    want to avoid moving the motors to avoid damage or injury.
    [servo.c, stepper.c]
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2026-05-30 Force reenable CAN bus on CAN off if configured
    Sometimes modules end up in a bus off state if the CAN bus is noisy
    enough. However, the bus is not necessarily noisy to the point of it
    being a major problem, so in that case this option is provided to force
    reenable the CAN bus if a bus off state is triggered.
    WARNING: This is a workaround that should be used with caution. If a
    module actually ends up with a major error such that it starts sending
    a ton of error frames, forcing it to be turned back on after a bus off
    state will keep on clogging the bus with error frames.
    [main.c, robot_shoulder_module.c]
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2026-05-30 Make each call to xTaskCreate self-contained
    Some of the calls to xTaskCreate depended on an error variable that
    hadn't been declared yet or was of the wrong type. Making all calls to
    xTaskCreate self-contained in their own scope avoids this and other
    scope pollution issues.
    [main.c, robot_shoulder_module.c]
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2026-06-05 HS422: Fix incorrect types when printing
    [HS422_led.c]
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2026-06-08 Hand motor: Fix incorrect IMU task period
    [main.c]
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2026-06-08 Servo: Fix not reversing angles in pulse_width_to_angle
    [servo.c]
2026-06-08 Hand motor: Reverse wrist rotation
    This makes the wrist and upper arm rotate in the same direction for
    increasing or decreasing angles.
    [main.c]
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2026-06-08 Remove resolved fixmes and todos
    [adc_manager.c, continuous_servo.c, robot_shoulder_module.c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]
2026-06-08 Fix order of FreeRTOS task creation
    The reenable CAN task should be created before the CAN rx task and the
    motor update task should be created last of all to avoid motors not
    being updated if later tasks for some reason fail to be created and abort.
    [main.c, robot_shoulder_module.c]
2026-06-08 Remove or replace asserts
    [adc_manager.c]
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
